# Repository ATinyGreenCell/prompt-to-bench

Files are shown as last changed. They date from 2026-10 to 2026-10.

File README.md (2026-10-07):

# Prompt to Bench: language models as a no-CAD entry point to 3D printing for biology labs



**Sebastian S. Cocioba** ([ORCID 0000-0002-6821-2996](https://orcid.org/0000-0002-6821-2996); [@ATinyGreenCell](https://github.com/ATinyGreenCell)), Binomica Labs, and contributors

*Living preprint, v0.2 (7 October 2026). This README **is** the paper. Corrections, tasks, designs, models and languages are welcome; see [How to contribute](#how-to-contribute). How it was built, prompt by prompt, is in the [build log](meta/BUILD_LOG.md).*

> **In this repository:** the paper (this page) · [student tutorial](tutorial/README.md) and [setup guide](tutorial/SETUP.md) · [16 parametric OpenSCAD lab designs](designs/) · [the Prompt-to-Bench benchmark](bench/) · [`scadreport`](tools/scadreport.py), a geometry-feedback tool for any chatbot · [audits](meta/audits/) · licences: text CC BY 4.0, designs CERN-OHL-P-2.0, code MIT.

---

## Abstract

Biology labs run on small plastic parts: tube racks, gel combs, adapters, knobs, brackets and housings. A desktop 3D printer makes them for cents, but designing them has required CAD skills most biologists never learn. Language models lower that barrier when the CAD is written as code: the user describes a part in words and measured numbers, the model writes an OpenSCAD program, and the user renders, checks and prints it. We describe this workflow and the practices we use to make it reliable, and release 16 parametric, geometry-checked designs across four kinds of lab prints (benchware, tools, quick fixes and parts of instruments; 33.7 h and about US$13 of PLA on a Prusa MK4), a benchmark that scores model-written OpenSCAD against hidden geometric checks, and a tool that measures the part a model actually built. Two hosted models passed nearly every task: Claude Sonnet 5.5 16 of 16 on the first try, Claude Haiku 4.5 14 of 16 within three attempts. None of the open-weight models (0.4-6.6 GB) we ran offline on a 2022 laptop CPU passed a task (the Qwen3.5 9B run is still being completed): the code models mostly wrote syntax OpenSCAD cannot parse and repeated the same file after feedback, and the reasoning models ran out of tokens. The best small models (Gemma 4 E2B and E4B) rendered most parts but rarely got their dimensions right. With this protocol, no open-weight model small enough for a typical student laptop is yet a usable design assistant; with a hosted model, the workflow already produces correct parts. We have not yet tested it with users who lack CAD experience.

---

## 1. Introduction

Every biology lab depends on a long tail of small, specific objects: a rack for the tubes this lab actually uses, a comb for a home-made gel tray, an adapter between two consumables, a replacement for the knob that cracked. Commercial versions are expensive, slow to arrive or not made at all. A decade of "open labware" has shown that printed and open-source equipment can match commercial tools at a fraction of the cost ([Pearce 2012](#pearce2012); [Baden et al. 2015](#baden2015); [Coakley & Hurt 2016](#coakley2016); [Pearce 2020](#pearce2020)), and that it matters most where budgets and supply chains are thinnest ([Maia Chagas 2018](#maiachagas2018); [Wenzel 2023](#wenzel2023)). In one collection of 26 printable lab items, which this author co-wrote, printed versions cost on average 8.18% of their commercial equivalents ([McNair et al. 2024](#mcnair2024)).

The printer is no longer the bottleneck; design is. One of the most widely used scripting tools for parametric open labware is **OpenSCAD** ([OpenSCAD developers](#openscad); [Machado et al. 2019](#machado2019)), in which a part is a short program of solids, Boolean operations and loops. It underlies the OpenFlexure microscope ([Collins et al. 2020](#collins2020)), the FlyPi ([Maia Chagas et al. 2017](#maiachagas2017)), a syringe-pump library ([Wijnen et al. 2014](#wijnen2014)), printable optics ([Zhang et al. 2013](#zhang2013)) and a steady stream of recent biology tools ([Subbaraman et al. 2024](#subbaraman2024); [Keene-Snickers et al. 2025](#keenesnickers2025); [Yamazaki et al. 2025](#yamazaki2025); [Bhupathi et al. 2026](#bhupathi2026); [Algarín et al. 2026](#algarin2026)). Its users find spatial reasoning, validation and debugging the hard parts ([Gonzalez Avila et al. 2024](#gonzalezavila2024)).

Because OpenSCAD designs are text, a language model can draft them from a plain-language description. GPT-4 has been used this way for microfluidic components ([Nelson et al. 2023](#nelson2023)), benchmarks of frontier models find OpenSCAD among the most reliable code-CAD formats ([Jones et al. 2025](#jones2025); [Yang et al. 2026](#yang2026)), and OpenSCAD's developers are building an experimental assistant that talks to a local model by default ([OpenSCAD GSoC 2026](#openscadai2026)). In our lab, a hosted frontier model (Claude) and OpenSCAD now take routine parts from idea to a print-ready file in minutes, which is what prompted this paper.

Access to that combination is uneven. In 2025, 2.2 billion people were offline, and fixed broadband cost more than a quarter of average income in low-income countries ([ITU 2025](#itu2025)). Generative-AI use reached 24.7% of people in the Global North and 14.1% in the Global South ([Microsoft AI Economy Institute 2026](#microsoft2026)). Hosted models cost money, are not offered everywhere ([Anthropic, n.d.](#anthropicregions)), charge more per word for many non-English languages ([Ahia et al. 2023](#ahia2023)) and can change availability at short notice ([Anthropic 2026](#anthropic2026)); non-native English speakers already pay heavily to do science in English ([Amano et al. 2023](#amano2023)). **Open-weight** models running offline on a student's laptop could close much of this gap, but there are reasons for doubt: OpenSCAD is a very low-resource programming language ([§5.5](#55-what-to-expect-from-open-models)), and open-weight models, even at 8-70B parameters, have done poorly at CAD code without fine-tuning ([Badagabettu et al. 2024](#badagabettu2024); [Alrashedy et al. 2025](#alrashedy2025); [Dong et al. 2026](#dong2026)).

We ask three practical questions:

1. **Workflow.** What process, prompts and checks let someone without CAD training get a correct, printable lab part from a language model?
2. **Model size.** What is the smallest open-weight model that is useful for this, offline, on an ordinary laptop?
3. **Language.** Does writing the request in Spanish, Hindi or Swahili change the outcome? (We could test this only for one hosted model.)

**Contributions.**

- A workflow and best-practice rules, with a copy-paste starter prompt ([§3](#3-the-workflow), [§4](#4-best-practices)).
- 16 parametric OpenSCAD lab designs in four categories ([§2](#2-what-labs-print-four-kinds-of-parts), [`designs/`](designs/)).
- `scadreport`, a tool that reports what an OpenSCAD file actually builds - size, holes, spacing, overhangs - in text any chatbot can read ([`tools/`](tools/)).
- **Prompt-to-Bench-16**, 16 design requests with hidden, symmetry-aware geometric checks ([§5](#5-benchmark-prompt-to-bench-16)).
- An evaluation of 14 open-weight models running CPU-only and offline, with two hosted Claude models as a reference and a language ablation ([§6](#6-results)).
- A student tutorial ([`tutorial/`](tutorial/README.md)) and a public log of how this repository was built with an AI assistant ([`meta/`](meta/)).

## 2. What labs print: four kinds of parts

| Kind | Examples | What must be right | Typical risk |
|---|---|---|---|
| **Benchware** (holds, organises, stores) | tube and slide racks, plate-format holders, pipette stands | hole counts, spacing, standard footprints (e.g. ANSI/SLAS microplate) | low - wrong sizes waste plastic |
| **Tools** (used in a protocol) | gel combs, micropestles, funnels, sowing templates | key dimensions, surface finish, materials | low-moderate - contamination, chemical attack |
| **Quick fixes** (replace or adapt a part) | knobs, tube adapters, hose barbs, clips | a precise fit to an existing object | moderate - fit and load |
| **Full hardware** (parts of instruments) | stirrer housings, motor brackets, enclosures, gel tanks | interfaces, fasteners, assembly, electronics | higher - mechanical, electrical, biosafety ([§8](#8-safety-and-responsibility)) |

Our 16 designs cover all four kinds (Figure 1). Each is one OpenSCAD file with every dimension as a named parameter in [Customizer](https://files.openscad.org/documentation/manual/Customizer.html) sections, modelled in print orientation, with print, fit and safety notes in its header. All print without supports; the only bridges are short (at most about 6 mm): the ceilings of the knob and adapter bores, the crowns of the bracket's M3 holes and the enclosure's cable hole, and the slide rack's drain channels. Sliced with PrusaSlicer ([Prusa Research](#prusaslicer)) for an Original Prusa MK4 with the stock 0.20 mm profile, the set takes 33.7 h and 508 g of PLA, about US$13 (Table 1).

The library has two versions on purpose. The benchmark's answer keys are frozen in [`bench/reference/`](bench/reference/): each is exactly what its prompt asks for. The files in [`designs/`](designs/) are their lab-ready successors, revised after a mechanical and biological audit and an adversarial review ([`meta/audits/`](meta/audits/)): wider clearances for tubes, slots that drain, standoffs so stirrer magnets clear the plate, a gel tank whose electrodes sit under the buffer, and explicit warnings where a part could be misused (for example, never spin the tube adapter in a centrifuge). The designs are geometry-checked and sliced; physical print-and-fit validation is in progress.

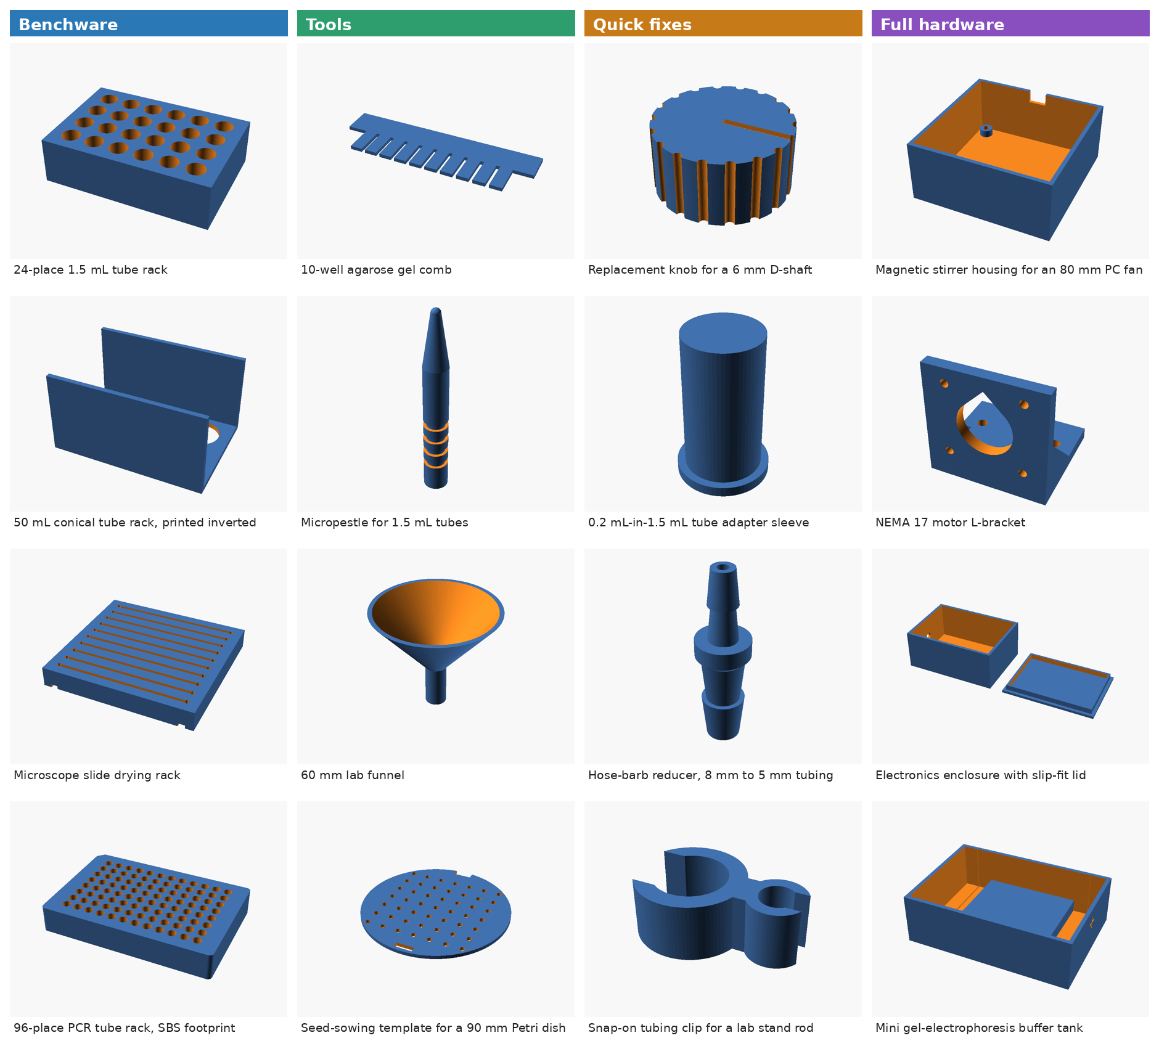
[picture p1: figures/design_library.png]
Renders of the 16 designs in four columns: benchware, tools, quick fixes, full hardware


**Figure 1.** The 16 lab-ready designs in [`designs/`](designs/).

<details>
<summary><b>Table 1.</b> Print-time and filament estimates, Original Prusa MK4 (click to expand)</summary>

<!-- AUTO:table-prints -->
| Part | Kind | Print time | PLA (g) | Material cost (US$) |
|---|---|---:|---:|---:|
| 24-place 1.5 mL tube rack | Benchware | 5h 26m 54s | 78.7 | 1.97 |
| 50 mL conical tube rack, printed inverted | Benchware | 4h 9m 34s | 69.0 | 1.73 |
| Microscope slide drying rack | Benchware | 2h 46m 43s | 45.6 | 1.14 |
| 96-place PCR tube rack, SBS footprint | Benchware | 8h 8m 41s | 92.9 | 2.32 |
| 10-well agarose gel comb | Tools | 11m 32s | 2.7 | 0.07 |
| Micropestle for 1.5 mL tubes | Tools | 26m 34s | 1.9 | 0.05 |
| 60 mm lab funnel | Tools | 37m 44s | 9.3 | 0.23 |
| Seed-sowing template for a 90 mm Petri dish | Tools | 50m 24s | 11.8 | 0.30 |
| Replacement knob for a 6 mm D-shaft | Quick fixes | 21m 7s | 5.0 | 0.12 |
| 0.2 mL-in-1.5 mL tube adapter sleeve | Quick fixes | 10m 41s | 1.5 | 0.04 |
| Hose-barb reducer, 8 mm to 5 mm tubing | Quick fixes | 18m 33s | 1.7 | 0.04 |
| Snap-on tubing clip for a lab stand rod | Quick fixes | 6m 49s | 1.5 | 0.04 |
| Magnetic stirrer housing for an 80 mm PC fan | Full hardware | 3h 7m 49s | 53.9 | 1.35 |
| NEMA 17 motor L-bracket | Full hardware | 59m 51s | 14.2 | 0.35 |
| Electronics enclosure with slip-fit lid | Full hardware | 1h 40m 19s | 33.9 | 0.85 |
| Mini gel-electrophoresis buffer tank | Full hardware | 4h 18m 57s | 84.4 | 2.11 |
| **All 16 parts** | | **33.7 h** | **508** | **12.71** |
<!-- /AUTO:table-prints -->

PrusaSlicer 2.9.6, stock "0.20mm SPEED @MK4 0.4" profile and "Prusament PLA @PG" for every part - not the finer per-part settings some headers recommend, which take longer. Mass assumes 1.24 g/cm³; cost assumes US$25/kg. Reproduce with `python tools/slice_library.py`.
</details>

## 3. The workflow

```mermaid
flowchart LR
    A["1 Measure<br/>calipers, photos"] --> B["2 Specify<br/>starter prompt + numbers"]
    B --> C["3 Generate<br/>model writes .scad"]
    C --> D{"4 Render + check<br/>OpenSCAD + scadreport"}
    D -- "errors or wrong numbers" --> E["5 Feed back<br/>paste messages / report"]
    E --> C
    D -- "matches the spec" --> F["6 Slice<br/>PrusaSlicer"]
    F --> G["7 Print a test coupon"]
    G --> H{"Fits?"}
    H -- "no: change a parameter" --> D
    H -- "yes" --> I["8 Print, use, share<br/>.scad + settings + photo"]
```

**Figure 2.** The model does the CAD; the person measures, checks and decides. Steps 4-5 can be run by an agent such as Claude Code or by hand with any chatbot.

Whatever the model, two features of the loop do most of the work.

**The specification carries the knowledge.** The user gives measured numbers, the print orientation and the coordinate frame ("the base lies on the bed at z = 0"). The model is never asked to remember a tube diameter or a fan's hole pattern; even standard dimensions - ANSI/SLAS microplate footprints, 80 mm fan holes, NEMA 17 bolt patterns - go into the request ([ANSI/SLAS 2004](#slas2004); [SUNON](#sunon); [Oriental Motor](#orientalmotor)).

**The model must be shown what it built.** A language model cannot see its part. When OpenSCAD fails, its messages go back to the model. When the file renders but the part is wrong, the useful feedback is a measurement, not "it's wrong". `scadreport` renders the file and reports whether it is one watertight solid, its bounding box, volume, bed contact and overhangs, and horizontal slices at up to ten representative heights - each listing every hole's shape, size and grid spacing. For a rack whose pitch and hole depth came out wrong:

```
BOUNDING BOX: X -53.00 .. 53.00 (size 106.00) | Y -36.00 .. 36.00 (size 72.00) | Z 0.00 .. 30.00 (size 30.00) mm
  z=1.50: 1 solid region [...]; 24 holes: 24 x circle d=11.19 [6 x 4 grid (X x Y), pitch X 15.00 / Y 15.00, ...]
  z=15.00: 1 solid region [...]; 24 holes: 24 x circle d=11.19 [6 x 4 grid (X x Y), pitch X 15.00 / Y 15.00, ...]
```

The request asked for a 16 mm pitch and a 5 mm solid floor. The report shows a 15 mm pitch and holes at z = 1.5, so the floor is missing. The report knows nothing about the request, so it works for any part.

## 4. Best practices

These rules come from our own use of the workflow, the benchmark and the literature, and complement general guides to 3D printing in chemistry and biology labs ([Pamidi et al. 2024](#pamidi2024); [Saggiomo 2022](#saggiomo2022)).

1. **Measure; don't rely on memory - yours or the model's.** Give caliper numbers for everything that must fit.
2. **State the print orientation and the frame.** Say which face is on the bed at z = 0 and which way is +X. Many "wrong" parts are right shapes, upside down or in the wrong place.
3. **Use a starter prompt.** It fixes the style: millimetres, named parameters, built-in OpenSCAD only, cutters that overshoot faces, `$fn` for round holes, loops for arrays ([`bench/prompts/system.md`](bench/prompts/system.md)). Best-practice lists in the prompt also helped GPT-4 in earlier CAD work ([Makatura et al. 2023](#makatura2023)).
4. **Once a design works, change its numbers - don't regenerate it.** The `.scad` file becomes a template for the next lab.
5. **Check every part against the request.** Paste OpenSCAD's messages or a `scadreport` back into the chat when something is wrong.
6. **Print a coupon first.** A 2-3 mm slice with the critical holes takes minutes. FDM holes print undersized ([Slic3r manual](#slic3r)): start at about 0.3-0.5 mm clearance per side for parts that should drop in (tubes in racks), 0.2-0.3 mm for sliding fits, and calibrate for your printer and material: accuracy depends on speed, temperature and layer height ([Prusa Research, n.d.](#prusamodeling); [Popescu et al. 2023](#popescu2023); [Li et al. 2025](#li2025)).
7. **Design for the printer.** A flat face on the bed, overhangs under about 45°, no long bridges, walls of at least two extrusion widths. Print upside down when that removes supports; four of our designs (the 50 mL rack, the tube adapter, the enclosure lid and the stirrer housing) are modelled that way.
8. **Choose material for the lab.** PLA softens around 55-60 °C: no autoclaves, hot baths or heat blocks. Printed PETG, PP and PC also deformed in 121 °C autoclave tests ([Pérez Davila et al. 2021](#perezdavila2021); [Rynio et al. 2022](#rynio2022); [Popescu et al. 2025](#popescu2025)); PETG's heat deflection temperature is 68 °C ([Prusament TDS](#prusament)). Let agarose cool to 50-60 °C before it meets a printed comb. Brief wipes with 70% ethanol, isopropanol or dilute hypochlorite are fine on PLA ([Vaňková et al. 2020](#vankova2020)); long soaks weaken parts ([Kaptan 2025](#kaptan2025)), and PETG is attacked by acetone, phenol and chloroform.
9. **Know what not to print.** No rotors or adapters for commercial centrifuges ([Eppendorf](#eppendorf)), pressure vessels, mains-powered enclosures without proper electrical design ([IEC 61010-1](#iec61010)), or anything that touches patients ([§8](#8-safety-and-responsibility)).
10. **Share the source, not just the STL.** The `.scad` file is the source of open hardware ([Bonvoisin et al. 2017](#bonvoisin2017); [Diederich et al. 2022](#diederich2022)). Add print settings, a photo, and the model and prompt that produced it.
11. **Keep private work local.** Do not paste unpublished or client designs into hosted services you do not control.
12. **Pick the model for the job.** In our tests only the hosted models produced correct parts. Small open-weight models are worth trying offline, but check everything they produce, and expect to fix the code yourself ([§6](#6-results)).

## 5. Benchmark: Prompt-to-Bench-16

### 5.1 Tasks

Each task is a request as a careful student would write it after measuring: dimensions in millimetres, the print orientation, the frame where it matters, and plain-language features. There are four tasks per category (Table 2), covering blind and through holes, 1-D and 2-D arrays (up to 96 holes in the ANSI/SLAS footprint), slots, teeth, revolved profiles, polar arrays, D-shaped bores, open rings, horizontal holes, multi-part layouts and a clearance fit. Prompts and checks are in [`bench/tasks.yaml`](bench/tasks.yaml); the frozen answer keys are in [`bench/reference/`](bench/reference/).

| Category | Task | What it exercises |
|---|---|---|
| Benchware | 24-place 1.5 mL tube rack | block, blind holes, 6 x 4 grid |
| Benchware | 50 mL conical tube rack, printed inverted | print orientation, through holes, walls |
| Benchware | Microscope slide drying rack | ten 1.6 mm slots |
| Benchware | 96-place PCR tube rack, SBS footprint | standard footprint, 96-hole grid, orientation chamfer |
| Tools | 10-well agarose gel comb | flat 2-D profile, tooth array |
| Tools | Micropestle for 1.5 mL tubes | stacked primitives, cone, grooves at given heights |
| Tools | 60 mm lab funnel | hollow solid of revolution, open ends |
| Tools | Seed-sowing template for a 90 mm Petri dish | disc, 49-hole grid, orientation notch |
| Quick fixes | Replacement knob for a 6 mm D-shaft | D-shaped bore, 18-groove polar array, aligned pointer |
| Quick fixes | 0.2 mL-in-1.5 mL tube adapter sleeve | concentric cylinders, upside-down printing |
| Quick fixes | Hose-barb reducer, 8 mm to 5 mm tubing | revolved sawtooth profile, through bore |
| Quick fixes | Snap-on tubing clip for a lab stand rod | 2-D Booleans, open rings, explicit coordinates |
| Full hardware | Magnetic stirrer housing for an 80 mm PC fan | shelled box, bolt pattern, cable notch |
| Full hardware | NEMA 17 motor L-bracket | horizontal holes, bolt patterns, gussets |
| Full hardware | Electronics enclosure with slip-fit lid | two bodies, 0.2 mm clearance |
| Full hardware | Mini gel-electrophoresis buffer tank | internal platform, chambers, holes |

**Table 2.** The 16 tasks. They test whether a model follows a specification; the lab-ready parts in [`designs/`](designs/) differ where real use called for it ([§2](#2-what-labs-print-four-kinds-of-parts)).

### 5.2 Hidden geometric checks

The model never sees the checks. A candidate is rendered with OpenSCAD's Manifold kernel ([Lalish et al.](#manifold)), normalised (bounding-box centre at the origin in XY, lowest point at z = 0) and tested with:

- **global checks:** bounding box, number of bodies, watertightness, volume relative to the reference;
- **horizontal sections:** number of solid regions and holes, hole sizes, positions and grids, section areas;
- **probe points** that must be solid or empty (notches, chamfers, horizontal holes);
- **line and arc probes** that count solid intervals (comb teeth, grip grooves).

Position-dependent checks are evaluated under all eight symmetries of the bed (90° rotations and mirroring), which do not change how a part prints, and the best match is kept. A part passes only if every check passes. Absolute tolerances are 0.15-0.9 mm (most 0.3-0.5 mm, tighter for the 0.2 mm clearance fit, looser where the prompt allows two readings), plus 4-35% on areas and volumes; they are set to accept every correct reading of the prompt, not to mimic print accuracy.

[`bench/build_refs.py`](bench/build_refs.py) confirms that the references pass their own checks, still pass after rotation, mirroring and translation, fail when scaled by 3%, and pass no other task's checks. These tests show the checks are self-consistent, not that every correct design passes or every wrong one fails. Two audits found both kinds of error. One false negative: "a 1.6 mm wall everywhere" on the funnel can be measured horizontally (our reference) or perpendicular to the cone (+24% volume), so we widened that task's volume tolerance. Three false positives: a comb with nine teeth or the wrong tooth pitch, a pestle with one grip groove instead of four, and a knob with a 7 mm bore instead of 12 mm all passed (two comb checks shared a name, so one silently replaced the other). We fixed the checks and added these parts to `build_refs.py` as known-wrong cases that must fail. Re-checking every saved hosted-model attempt with [`bench/rescore.py`](bench/rescore.py) changed the funnel verdict and no other; re-checking the local-model attempts changed partial scores but no verdict. Building the checks also caught an error in our own design: a 7 x 7 grid at 10 mm pitch put the corner holes through the rim of the 85 mm seed template.

### 5.3 Protocol

- **Prompt:** the same system prompt ([`bench/prompts/system.md`](bench/prompts/system.md)) for every model, then the task text.
- **Code extraction:** the longest OpenSCAD-labelled fenced block (otherwise any fenced block, the text after an unclosed fence, or the whole reply if it contains OpenSCAD calls). Local replies stop once a complete block has arrived, so in practice their first block counts.
- **Feedback:** a part that fails gets one message and another try, up to three attempts: OpenSCAD's own errors when nothing rendered, otherwise the `scadreport` measurement with an instruction to compare it with the specification. The hidden checks are never shown, but they decide *whether* feedback is sent, so "passed within three attempts" is an optimistic bound on what a user who must spot errors alone would get.
- **Local models:** Ollama 0.30.11, 4-bit weights (Q4_K_M), temperature 0.2, top-p 0.95, a fixed seed per attempt, 8,192-token context, "thinking" requested off where a model supports the switch. Replies end at 2,048 tokens, when a complete OpenSCAD block has arrived, or when the model repeats itself verbatim. Qwen2.5-Coder 3B and 7B ran with an earlier 1,024-token cap that never applied (their longest reply was 723 tokens); we raised the cap after a first pass cut off Gemma 4 E4B and others, and reran those models.
- **Hosted reference:** Claude Haiku 4.5 and Claude Sonnet 5.5 through the Claude Code command line in print mode, with our system prompt, tools disabled and otherwise vendor defaults: the API's default temperature (the CLI cannot set it) and no seed. Haiku used extended thinking (median about 10,000 output tokens per reply, range 4,100-23,500); Sonnet answered directly (320-1,430 tokens, 3.5-11.5 s per reply). This is Claude at its defaults, not an equal-cost comparison.
- **Hardware:** a 2022 laptop, Intel Core i7-1260P (12 cores, 16 threads), 16 GB RAM, no discrete GPU, Ubuntu, OpenSCAD 2026.10.01 (development snapshot), PrusaSlicer 2.9.6. Local models ran one at a time, but some runs overlapped other work on the same laptop (for example the hosted language run, whose rendering uses the CPU), so timings are indicative (roughly ±20%), not clean benchmarks.

### 5.4 Models

<!-- AUTO:table-models -->
| Model | Family | Parameters | Download | Licence |
|---|---|---|---:|---|
| Qwen2.5-Coder 0.5B (`qwen2.5-coder:0.5b`) | Qwen2.5-Coder | 0.49B | 0.4 GB | Apache-2.0 |
| Qwen2.5-Coder 1.5B (`qwen2.5-coder:1.5b`) | Qwen2.5-Coder | 1.54B | 0.99 GB | Apache-2.0 |
| Qwen2.5 1.5B (general) (`qwen2.5:1.5b`) | Qwen2.5 | 1.54B | 0.99 GB | Apache-2.0 |
| Qwen3.5 2B (`qwen3.5:2b-q4_K_M`) | Qwen3.5 | 2.27B | 1.9 GB | Apache-2.0 |
| Qwen2.5-Coder 3B (`qwen2.5-coder:3b`) | Qwen2.5-Coder | 3.09B | 1.9 GB | Qwen Research (non-commercial) |
| Llama 3.2 3B (`llama3.2:3b`) | Llama 3.2 | 3.21B | 2 GB | Llama 3.2 Community |
| Granite 4.2 3B (`granite4.2:3b`) | Granite 4.2 | 3B | 2.2 GB | Apache-2.0 |
| Ministral 3 3B (`ministral-3:3b`) | Ministral 3 | 3.4B | 3 GB | Apache-2.0 |
| Qwen3.5 4B (`qwen3.5:4b-q4_K_M`) | Qwen3.5 | 4.66B | 3.3 GB | Apache-2.0 |
| Gemma 4 E2B (`gemma4:e2b-it-q4_K_M`) | Gemma 4 | 2.3B effective, 5.1B with per-layer embeddings | 4.6 GB | Apache-2.0 |
| Qwen2.5-Coder 7B (`qwen2.5-coder:7b`) | Qwen2.5-Coder | 7.61B | 4.7 GB | Apache-2.0 |
| LFM2.5 8B-A1B (MoE) (`lfm2.5:8b-a1b-q4_K_M`) | LFM2.5 | 8.3B total, ~1.5B active per token | 5.2 GB | LFM Open v1.0 (revenue cap) |
| Gemma 4 E4B (`gemma4:e4b-it-q4_K_M`) | Gemma 4 | 4.5B effective, 8B with per-layer embeddings | 6.6 GB | Apache-2.0 |
| Qwen3.5 9B (`qwen3.5:9b-q4_K_M`) | Qwen3.5 | 9.65B | 6.6 GB | Apache-2.0 |
| Claude Haiku 4.5 (hosted) (`claude:claude-haiku-4-5`) | Claude | - | hosted | proprietary API |
| Claude Sonnet 5.5 (hosted) (`claude:claude-sonnet-5-5`) | Claude | - | hosted | proprietary API |
<!-- /AUTO:table-models -->

The 14 local models come from eight families: Qwen2.5-Coder ([Hui et al. 2024](#hui2024)), Qwen2.5 ([Qwen Team 2024](#qwen2024)), Qwen3.5 ([Qwen Team 2026](#qwen2026)), Gemma 4 ([Gemma Team 2026](#gemma2026)), Ministral 3 ([Liu et al. 2026](#liu2026)), Granite 4.2 ([IBM Granite Team 2026](#ibm2026)), LFM2.5 ([Liquid AI 2026](#liquid2026)) and Llama 3.2 ([Meta 2024](#meta2024)), all run through Ollama ([Ollama](#ollama)) on llama.cpp ([Gerganov et al.](#llamacpp)) as 4-bit GGUF files ([Kawrakow 2023](#kawrakow2023)). Sizes are Ollama download sizes; parameter counts and licences are from the model cards (accessed 5 October 2026). "Open-weight" is not open source, and licences matter for labs that sell services: the Qwen2.5-Coder 3B weights are non-commercial, LFM2.5 has a revenue threshold, and Llama 3.2 has its own licence ([Qwen 2024](#qwen3blicense); [Liquid AI 2026](#liquid2026); [Meta 2024](#meta2024)). Tags and digests are in [`bench/logs/model_digests.txt`](bench/logs/model_digests.txt).

### 5.5 What to expect from open models

**OpenSCAD is a low-resource language.** In The Stack, an openly licensed corpus used to pretrain many code models, OpenSCAD is about 0.03 GB of compressed data, against about 47 GB for Python and 1.6 GB for Lua ([Kocetkov et al. 2022](#kocetkov2022); [Lozhkov et al. 2024](#lozhkov2024)) - and Lua is itself the usual example of a "low-resource" language ([Cassano et al. 2024](#cassano2024)). Quantised 7B code models on a CPU-only laptop score below 50% on Lua benchmarks ([Nyamsuren 2025](#nyamsuren2025)).

**Open models have done poorly at CAD code without fine-tuning.** CodeLlama-70B produced "extremely bad" FreeCAD output ([Badagabettu et al. 2024](#badagabettu2024)); open models compiled less often than GPT-4 ([Alrashedy et al. 2025](#alrashedy2025)); on a 2026 assembly benchmark, open-weight models of 8B parameters and up scored about 3-4% against about 20% for the best closed models ([Dong et al. 2026](#dong2026)). Small-model successes come from fine-tuning on narrow CAD datasets ([Rukhovich et al. 2025](#rukhovich2025); [Govindarajan et al. 2026](#govindarajan2026); [Xie & Ju 2025](#xie2025)). We test models as a student would download them.

**"Minimal viable", defined before analysing local results.** A minimally viable local model passes at least **half of the 16 tasks within three attempts**, runs on a 16 GB laptop without a GPU, and needs a median of at most **10 minutes per task**; the minimal one is the smallest download that meets all three.

## 6. Results

### 6.1 Overall

<!-- AUTO:table-main -->
| Model | Download | Licence | Pass, 1st try | Pass, ≤3 tries (95% CI) | Renders 1st try | Median min/task | Tokens/s | Same code after feedback |
|---|---:|---|---:|---:|---:|---:|---:|---:|
| Claude Haiku 4.5 (hosted) | hosted | proprietary API | 11/16 | 14/16 (64-97%) | 15/16 | 1.9 | - | 2/8 |
| Claude Sonnet 5.5 (hosted) | hosted | proprietary API | 16/16 | 16/16 (81-100%) | 16/16 | 0.1 | - | 0/0 |
| Qwen2.5-Coder 0.5B | 0.4 GB | Apache-2.0 | 0/16 | 0/16 (0-19%) | 0/16 | 0.8 | 37.7 | 24/32 |
| Qwen2.5 1.5B (general) | 0.99 GB | Apache-2.0 | 0/16 | 0/16 (0-19%) | 2/16 | 1.0 | 22.0 | 27/32 |
| Qwen2.5-Coder 1.5B | 0.99 GB | Apache-2.0 | 0/16 | 0/16 (0-19%) | 1/16 | 1.4 | 12.8 | 32/32 |
| Qwen2.5-Coder 3B | 1.9 GB | Qwen Research (non-commercial) | 0/16 | 0/16 (0-19%) | 3/16 | 1.9 | 10.7 | 31/32 |
| Qwen3.5 2B | 1.9 GB | Apache-2.0 | 0/16 | 0/16 (0-19%) | 0/16 | 6.3 | 18.4 | 0/32 |
| Llama 3.2 3B | 2.0 GB | Llama 3.2 Community | 0/16 | 0/16 (0-19%) | 8/16 | 2.2 | 10.3 | 6/32 |
| Granite 4.2 3B | 2.2 GB | Apache-2.0 | 0/16 | 0/16 (0-19%) | 2/16 | 14.8 | 6.9 | 0/32 |
| Ministral 3 3B | 3.0 GB | Apache-2.0 | 0/16 | 0/16 (0-19%) | 1/16 | 3.6 | 9.0 | 0/32 |
| Qwen3.5 4B | 3.3 GB | Apache-2.0 | 0/16 | 0/16 (0-19%) | 1/16 | 15.2 | 8.3 | 0/32 |
| Gemma 4 E2B | 4.6 GB | Apache-2.0 | 0/16 | 0/16 (0-19%) | 12/16 | 3.6 | 18.6 | 3/32 |
| Qwen2.5-Coder 7B | 4.7 GB | Apache-2.0 | 0/16 | 0/16 (0-19%) | 1/16 | 3.1 | 5.8 | 32/32 |
| LFM2.5 8B-A1B (MoE) | 5.2 GB | LFM Open v1.0 (revenue cap) | 0/16 | 0/16 (0-19%) | 0/16 | 5.1 | 20.8 | 0/32 |
| Gemma 4 E4B | 6.6 GB | Apache-2.0 | 0/16 | 0/16 (0-19%) | 9/16 | 6.1 | 11.7 | 5/32 |
| Qwen3.5 9B *(partial)* | 6.6 GB | Apache-2.0 | 0/2 | 0/2 (0-66%) | 1/2 | 17.2 | 4.7 | 1/4 |
<!-- /AUTO:table-main -->

**Table 3.** Main results. "Renders 1st try" means the first file produced a non-empty solid, correct or not. Intervals are Wilson 95% intervals over the 16 tasks of a single run (over the tasks completed, for partial rows); they do not include run-to-run variation. "Same code after feedback" counts repair attempts that returned a byte-identical file.

The hosted models are at or near the ceiling. Claude Sonnet 5.5 passed all 16 tasks on the first try; Claude Haiku 4.5 passed 11 on the first try and 14 within three attempts, failing the 96-place rack (one chamfer probe) and the enclosure (a lid with a solid floor under its lip, +14% volume). With one run each, the two cannot be ranked (paired exact test on first tries, p = 0.06); the task set is too easy to separate hosted models of this class.

No local model passed a task. Every complete local model scored 0 of 16 (Wilson upper bound 19%), so none met the viability bar in [§5.5](#55-what-to-expect-from-open-models). The Qwen3.5 9B run is still being completed (2 of 16 tasks so far); its partial row is marked.

### 6.2 How far the local models got

<!-- AUTO:fig-tiers -->
<picture>
  <source media="(prefers-color-scheme: dark)" srcset="figures/fig_tiers_dark.png">
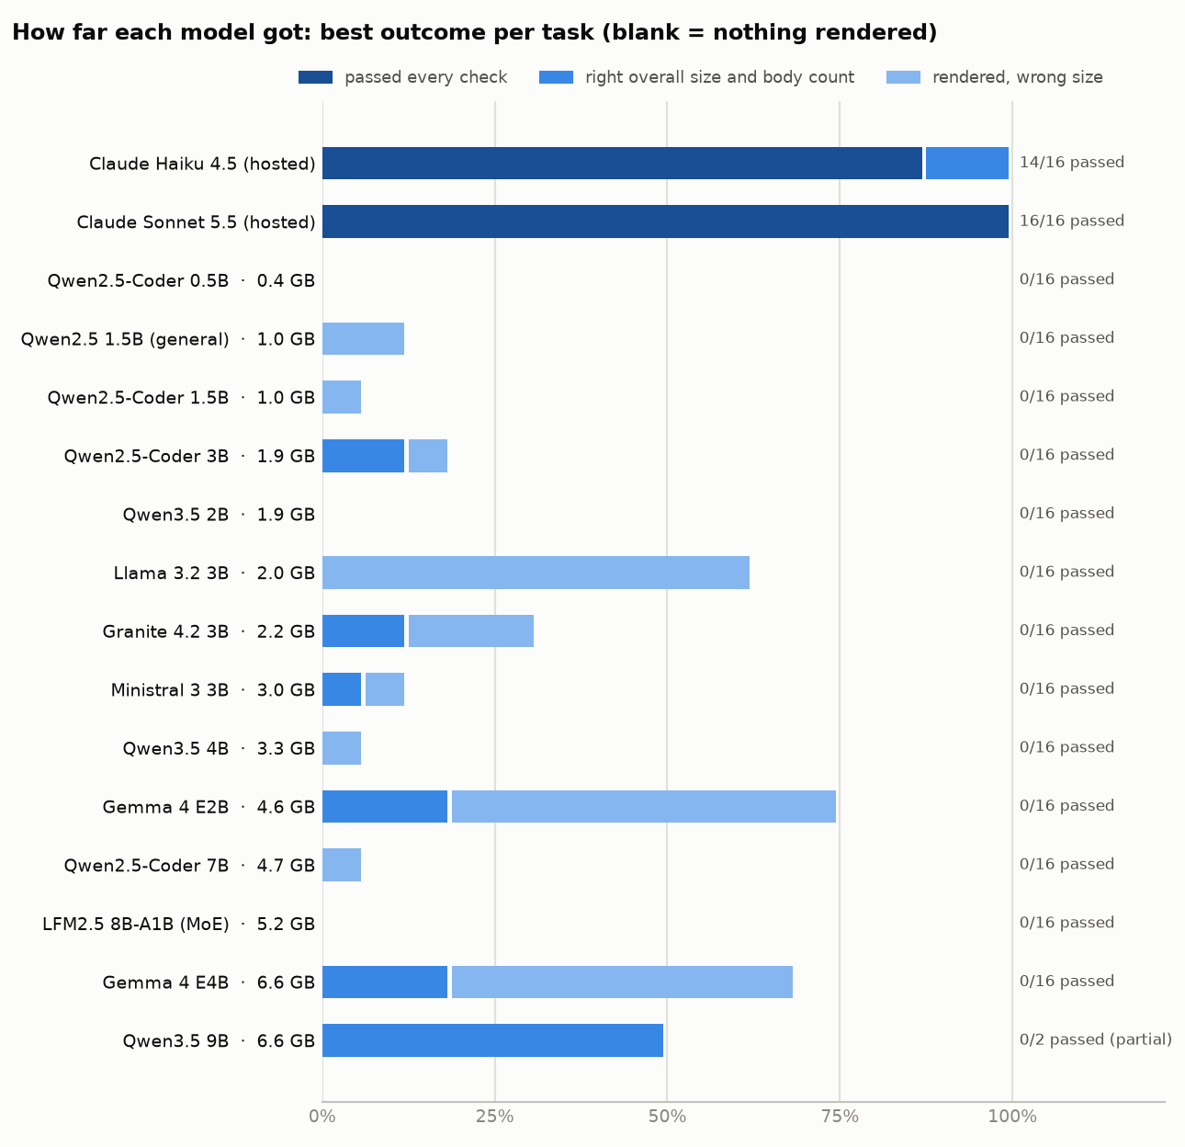
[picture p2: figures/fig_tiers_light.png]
Stacked bars of the best outcome each model reached per task
  
</picture>
<!-- /AUTO:fig-tiers -->

**Figure 3.** The best outcome each model reached per task, from nothing rendered (blank) to a part with the right overall size and body count, to a pass. Local models are ordered by download size.

<!-- AUTO:table-graded -->
| Model | Rendered (any try) | Right size and body count | Passed | Tasks with ≥ half the checks | First file treats geometry as a value | Attempts cut off (cap or loop) | Same code after feedback |
|---|---:|---:|---:|---:|---:|---:|---:|
| Claude Haiku 4.5 (hosted) | 16/16 | 16/16 | 14/16 | 16/16 | 0/16 | 0/24 | 2/8 |
| Claude Sonnet 5.5 (hosted) | 16/16 | 16/16 | 16/16 | 16/16 | 0/16 | 0/16 | 0/0 |
| Qwen2.5-Coder 0.5B | 0/16 | 0/16 | 0/16 | 0/16 | 0/16 | 27/48 | 24/32 |
| Qwen2.5 1.5B (general) | 2/16 | 0/16 | 0/16 | 0/16 | 6/16 | 15/48 | 27/32 |
| Qwen2.5-Coder 1.5B | 1/16 | 0/16 | 0/16 | 0/16 | 14/16 | 3/48 | 32/32 |
| Qwen2.5-Coder 3B | 3/16 | 2/16 | 0/16 | 2/16 | 11/16 | 0/48 | 31/32 |
| Qwen3.5 2B | 0/16 | 0/16 | 0/16 | 0/16 | 3/16 | 42/48 | 0/32 |
| Llama 3.2 3B | 10/16 | 0/16 | 0/16 | 0/16 | 2/16 | 1/48 | 6/32 |
| Granite 4.2 3B | 5/16 | 2/16 | 0/16 | 1/16 | 8/16 | 37/48 | 0/32 |
| Ministral 3 3B | 2/16 | 1/16 | 0/16 | 1/16 | 8/16 | 1/48 | 0/32 |
| Qwen3.5 4B | 1/16 | 0/16 | 0/16 | 0/16 | 5/16 | 39/48 | 0/32 |
| Gemma 4 E2B | 12/16 | 3/16 | 0/16 | 6/16 | 2/16 | 1/48 | 3/32 |
| Qwen2.5-Coder 7B | 1/16 | 0/16 | 0/16 | 0/16 | 15/16 | 0/48 | 32/32 |
| LFM2.5 8B-A1B (MoE) | 0/16 | 0/16 | 0/16 | 0/16 | 0/16 | 41/48 | 0/32 |
| Gemma 4 E4B | 11/16 | 3/16 | 0/16 | 6/16 | 3/16 | 5/48 | 5/32 |
| Qwen3.5 9B *(partial)* | 1/2 | 1/2 | 0/2 | 1/2 | 0/2 | 1/6 | 1/4 |
<!-- /AUTO:table-graded -->

**Table 4.** Graded outcomes. "Right size and body count": the bounding box and number of separate solids match, on any attempt. "Geometry as a value": the first file assigns shapes to variables (`rack = cube(...)`), which OpenSCAD cannot parse. "Cut off": attempts that ended at the token cap or in a verbatim loop.

The zeros hide three different failures:

- **Code models write a different language.** Qwen2.5-Coder 1.5B, 3B and 7B wrote "geometry as a value" in 11-15 of 16 first files - OpenSCAD written as if it were Python or JavaScript - and almost never produced a part.
- **Feedback changed nothing for them.** The same three models returned byte-identical code in 31-32 of 32 repair attempts, even with a new random seed; Qwen2.5-Coder 0.5B and the general Qwen2.5 1.5B did so in 24 and 27 of 32. A bare "syntax error, line 18" from OpenSCAD did not tell them what to change.
- **Reasoning models ran out of tokens.** With thinking requested off, Qwen3.5 and Granite 4.2 reasoned inside code comments, and LFM2.5 ignored the switch and wrote `<think>` reasoning in every reply. In the four complete runs (Qwen3.5 2B and 4B, Granite 4.2, LFM2.5), 37-42 of 48 attempts ended at the 2,048-token cap or in a loop. Their scores say as much about the protocol as about their design ability.

The closest were the Gemma 4 models (E2B and E4B), which rendered 11-12 of 16 parts and met half the checks on 6 tasks, but got the overall size right on only 3. The single best local attempt (Gemma 4 E4B, micropestle) failed one check: its grip grooves were 1.5 mm deep instead of 1 mm.

<!-- AUTO:fig-outcomes -->
<picture>
  <source media="(prefers-color-scheme: dark)" srcset="figures/fig_outcomes_dark.png">
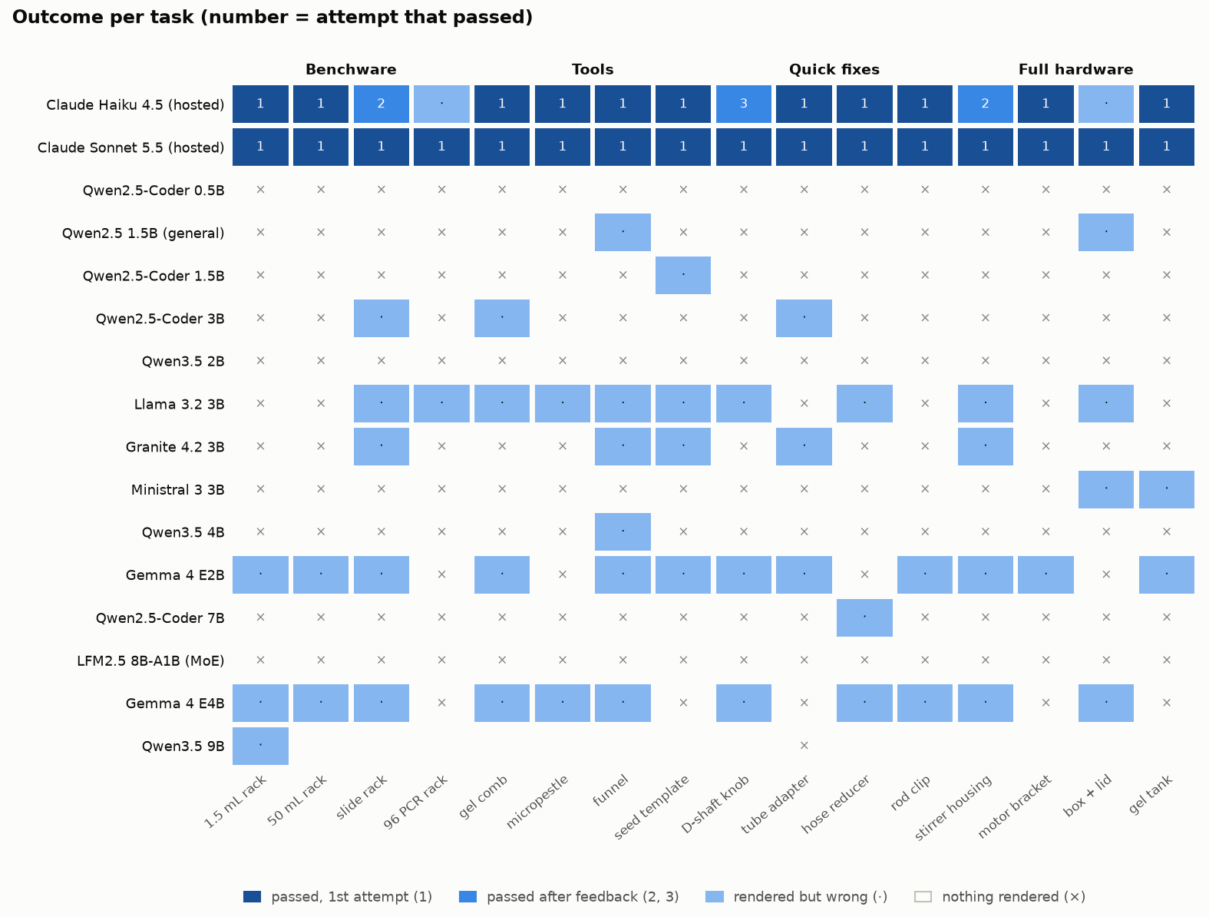
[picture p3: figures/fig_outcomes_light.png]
Grid of outcomes per model and task
  
</picture>
<!-- /AUTO:fig-outcomes -->

**Figure 4.** Outcome per model and task. Numbers give the attempt that passed; "·" rendered but never matched the specification; "×" nothing rendered.

<!-- AUTO:table-categories -->
| Model | Benchware | Tools | Quick fixes | Full hardware |
|---|---:|---:|---:|---:|
| Claude Haiku 4.5 (hosted) | 3/4 | 4/4 | 4/4 | 3/4 |
| Claude Sonnet 5.5 (hosted) | 4/4 | 4/4 | 4/4 | 4/4 |
| Qwen2.5-Coder 0.5B | 0/4 | 0/4 | 0/4 | 0/4 |
| Qwen2.5 1.5B (general) | 0/4 | 0/4 | 0/4 | 0/4 |
| Qwen2.5-Coder 1.5B | 0/4 | 0/4 | 0/4 | 0/4 |
| Qwen2.5-Coder 3B | 0/4 | 0/4 | 0/4 | 0/4 |
| Qwen3.5 2B | 0/4 | 0/4 | 0/4 | 0/4 |
| Llama 3.2 3B | 0/4 | 0/4 | 0/4 | 0/4 |
| Granite 4.2 3B | 0/4 | 0/4 | 0/4 | 0/4 |
| Ministral 3 3B | 0/4 | 0/4 | 0/4 | 0/4 |
| Qwen3.5 4B | 0/4 | 0/4 | 0/4 | 0/4 |
| Gemma 4 E2B | 0/4 | 0/4 | 0/4 | 0/4 |
| Qwen2.5-Coder 7B | 0/4 | 0/4 | 0/4 | 0/4 |
| LFM2.5 8B-A1B (MoE) | 0/4 | 0/4 | 0/4 | 0/4 |
| Gemma 4 E4B | 0/4 | 0/4 | 0/4 | 0/4 |
| Qwen3.5 9B | 0/1 | - | 0/1 | - |
<!-- /AUTO:table-categories -->

**Table 5.** Tasks passed within three attempts, by category (out of 4).

<!-- AUTO:table-failures -->
| Model | truncated | no code | syntax error | render error | no solid | timeout | wrong geometry | pass |
|---|---:|---:|---:|---:|---:|---:|---:|---:|
| Claude Haiku 4.5 (hosted) | 0 | 0 | 1 | 0 | 0 | 0 | 4 | 11 |
| Claude Sonnet 5.5 (hosted) | 0 | 0 | 0 | 0 | 0 | 0 | 0 | 16 |
| Qwen2.5-Coder 0.5B | 9 | 0 | 7 | 0 | 0 | 0 | 0 | 0 |
| Qwen2.5 1.5B (general) | 5 | 0 | 9 | 0 | 0 | 0 | 2 | 0 |
| Qwen2.5-Coder 1.5B | 1 | 0 | 11 | 1 | 2 | 0 | 1 | 0 |
| Qwen2.5-Coder 3B | 0 | 0 | 12 | 0 | 1 | 0 | 3 | 0 |
| Qwen3.5 2B | 15 | 0 | 0 | 1 | 0 | 0 | 0 | 0 |
| Llama 3.2 3B | 1 | 0 | 5 | 1 | 1 | 0 | 8 | 0 |
| Granite 4.2 3B | 12 | 0 | 1 | 0 | 1 | 0 | 2 | 0 |
| Ministral 3 3B | 0 | 0 | 13 | 0 | 2 | 0 | 1 | 0 |
| Qwen3.5 4B | 14 | 0 | 1 | 0 | 0 | 0 | 1 | 0 |
| Gemma 4 E2B | 0 | 0 | 4 | 0 | 0 | 0 | 12 | 0 |
| Qwen2.5-Coder 7B | 0 | 0 | 15 | 0 | 0 | 0 | 1 | 0 |
| LFM2.5 8B-A1B (MoE) | 16 | 0 | 0 | 0 | 0 | 0 | 0 | 0 |
| Gemma 4 E4B | 3 | 0 | 3 | 1 | 0 | 0 | 9 | 0 |
| Qwen3.5 9B | 0 | 0 | 1 | 0 | 0 | 0 | 1 | 0 |
<!-- /AUTO:table-failures -->

**Table 6.** Where each model's first attempt stopped: cut off (token cap or loop), no code, a syntax or other render error, no solid (empty or 2-D), a rendered part with the wrong geometry, or a pass.

### 6.3 Language

<!-- AUTO:fig-languages -->
<picture>
  <source media="(prefers-color-scheme: dark)" srcset="figures/fig_languages_dark.png">
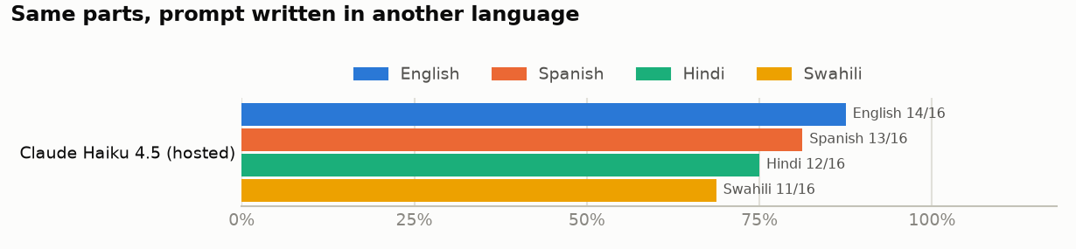
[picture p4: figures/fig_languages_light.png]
Pass rates for prompts in English, Spanish, Hindi and Swahili
  
</picture>
<!-- /AUTO:fig-languages -->

With Claude Haiku 4.5, requests in Spanish, Hindi and Swahili (system prompt in English) passed 13, 12 and 11 of 16 tasks within three attempts, against 14 in English; first-try passes were 12, 10 and 6 against 11. With one sample per task at the default temperature, none of these differences is statistically detectable (paired exact McNemar tests, p ≥ 0.375 for passes, p = 0.125 for Swahili first tries). Some failures recurred with the same failing check - the NEMA 17 bracket in all three translations (English passed it first time), and the 96-place rack's chamfer in English, Hindi and Swahili - so not all of the variation is sampling noise. We did not run the language ablation on local models, which passed nothing in English. A bug overwrote the generated code of the Spanish and Hindi runs (their scores were recorded first), so those two runs cannot be re-checked; it is fixed for future runs.

## 7. Global access

**Cost.** A Prusa MK4S costs about US$650-1,000 (kit vs assembled) and capable budget printers about US$200 ([Prusa Research](#prusaprice); [Bambu Lab](#bambuprice); [Creality](#crealityprice)). After that, parts are cheap: our 16-part library uses about US$13 of PLA. OpenSCAD, PrusaSlicer, Ollama and open-weight models are free; hosted models need a subscription or per-token payment, often in a currency labs cannot easily use.

**Connectivity.** The local workflow runs offline once installed; the obstacle is the one-time download of the software plus 0.4-6.6 GB per model. In nine of ten low-income economies a 5 GB mobile data basket costs more than 10% of monthly income ([ITU 2025b](#itu2025b)), so teaching labs, maker spaces and networks such as TReND ([Baden et al. 2020](#baden2020)) or GOSH ([GOSH 2017](#gosh2017)) should share models on USB drives or local mirrors.

**Availability.** Major hosted providers exclude a small set of countries and territories, including China, Russia and Iran ([Anthropic, n.d.](#anthropicregions); [OpenAI, n.d.](#openairegions); [Google, n.d.](#googleregions)); most low-income countries are supported. Access can still change: in June 2026 a US government directive suspended two frontier Anthropic models for "any foreign national" for 18 days while other models stayed available ([Anthropic 2026](#anthropic2026)). A local model cannot be switched off this way, and it keeps unpublished designs on the user's machine.

**Language.** Language models perform worse in many non-English languages ([Ahuja et al. 2023](#ahuja2023)), and code generation degrades more steeply for small open models than for frontier ones as prompts move to lower-resource languages ([Raihan et al. 2025](#raihan2025)). Our one-model test found no detectable effect ([§6.3](#63-language)).

**Hardware.** The test machine is a mid-range 2022 ultrabook with 16 GB of RAM; the 6.6 GB models ran on it alongside a desktop session with an 8,192-token context. We did not test larger models.

**Where this leaves a student without a subscription.** Today, the reliable path still runs through a hosted model; free tiers of hosted chatbots may be enough for simple parts (we did not test them). The parts of the workflow that do not depend on the model - measuring, writing a precise request, checking with `scadreport`, printing coupons, editing parameters - transfer completely, and so does the design library.

## 8. Safety and responsibility

- **Materials and sterilisation.**
  - Fresh FDM prints can be close to sterile off the nozzle ([Neches et al. 2016](#neches2016)), but handling ends that, and layer lines harbour biofilm ([Hall et al. 2021](#hall2021)). Ethanol disinfects but does not kill spores, so anything that touches media or cultures should be soaked, dried in a hood and treated as single use.
  - Printed PLA cannot be autoclaved ([Neijhoft et al. 2023](#neijhoft2023)), and printed PETG, PP and PC deformed at 121 °C in tests ([Rynio et al. 2022](#rynio2022); [Popescu et al. 2025](#popescu2025)); moulded PP labware is a different matter and is routinely autoclaved.
  - UV-C degrades PETG faster than PLA ([Amza et al. 2021](#amza2021)), and resin (SLA) prints can be toxic to sensitive organisms ([Macdonald et al. 2016](#macdonald2016)). Test printed materials in your own system before trusting them with cells or organisms.
- **Centrifuges.** Manufacturers require their own accessories ([Eppendorf](#eppendorf)), and biosafety guidance relies on certified sealed rotors or safety cups ([CDC & NIH 2020](#bmbl2020)). Our tube adapter fits a 1.5 mL rotor bore by design, so its header says, in capitals, never to spin it.
- **Electrical hardware.** Mains-powered devices fall under IEC 61010-1 ([IEC 2010](#iec61010)); keep DIY electronics at safe low voltage behind certified supplies. Gel electrophoresis runs at hazardous DC voltages: our tank does not include a lid or interlock, and its header says not to connect a power supply until one is built.
- **Printing.** Printers emit ultrafine particles and volatile organic compounds, more with ABS than with PLA ([Azimi et al. 2016](#azimi2016)); follow institutional ventilation guidance ([NIOSH 2020](#niosh2020)).
- **Distribution.** Open-hardware certification is not safety certification ([OSHWA 2026](#oshwa2026)). From 9 December 2026 the EU Product Liability Directive treats "digital manufacturing files" as products ([EU 2024](#eu2024)); anyone distributing printable designs commercially in the EU should take advice (this is not legal advice). Document hazards with each design, as hardware journals require ([HardwareX template](#hardwarex)).

## 9. Limitations

- **Scale.** Sixteen tasks, one run per model, one computer. Intervals are wide and do not include run-to-run variation.
- **Protocol choices decide some results.** Thinking was requested off and replies were capped at 2,048 tokens, so models that reason before answering (Qwen3.5, Granite 4.2, LFM2.5) were mostly cut off; with thinking on and a larger budget they might do better, at a large cost in CPU time. Local models ran at temperature 0.2, which made several repeat themselves exactly; Claude ran at its default temperature. Feedback was triggered by the hidden checks (an optimistic bound).
- **Who wrote the tasks.** The tasks, checks, reference designs and translations were drafted with Claude (Anthropic), which may favour Claude's phrasing; the hosted models are near ceiling, so the benchmark cannot rank them. Independent tasks would help.
- **The harness evolved during the study.** We fixed bugs and added robustness after the first runs; re-checking every saved attempt with the final checker changed one verdict (§5.2). Two language runs cannot be re-checked (§6.3).
- **Geometry is not function.** Passing means the part matches the request, not that it works; the designs have not yet been printed and measured systematically.
- **No user study.** We did not test the workflow with students or biologists who lack CAD experience; that it suits them is the author's experience, not a measured result.
- **Best-case prompts.** Our requests are complete and precise; real ones are vaguer.
- **Translations** have not yet been reviewed by native speakers.
- **Snapshot.** These results describe models available on 5 October 2026.

## 10. Conclusion

A language model plus OpenSCAD can already turn a measured, written request into a correct lab part - when the model is a hosted frontier model, the request carries measured numbers and the print orientation, and every part is checked before it is printed. Whether people without CAD training can run this loop unaided is the next thing to test. Under our protocol, no open-weight model small enough for a typical student laptop was yet a usable design assistant: the code models write OpenSCAD as if it were another language and do not use error messages, and the reasoning models run out of tokens before they finish. The gap is specific enough to close - examples of correct OpenSCAD in the prompt, error messages translated into instructions, thinking budgets that fit a laptop, or small models fine-tuned on code like the designs released here - and the benchmark is cheap to rerun on new models, hardware and languages.

---

## How to contribute

This is a living paper; contributions are credited and substantial ones earn authorship ([CONTRIBUTING.md](CONTRIBUTING.md)). Most useful:

- **Run the benchmark on your hardware** (`bench/run_bench.py`), especially in low-resource settings, and send the `results/` folder in a pull request.
- **Add a model** (one line in [`bench/models.yaml`](bench/models.yaml) plus a run) or **a task** from your lab ([`bench/tasks.yaml`](bench/tasks.yaml), validated with `python bench/build_refs.py`).
- **Review or add a language** in [`bench/prompts/translations.yaml`](bench/prompts/translations.yaml).
- **Print and measure** a design and report the fit with photos and caliper readings.
- **Translate the tutorial.**

## Reproducing this paper

```bash
python3 -m venv .venv && .venv/bin/pip install -r requirements.txt
.venv/bin/python bench/test_harness.py        # robustness tests (fake model, real OpenSCAD)
.venv/bin/python bench/build_refs.py          # validate the checker against the frozen references
bash bench/logs/pull_models.sh                # download the 14 local models (0.4-6.6 GB each)
bash bench/run_main_local.sh                  # local models via Ollama (hours on a CPU)
.venv/bin/python bench/analyze.py             # tables and figures in this README
```

Details, including the hosted reference and the language ablation, are in [`bench/README.md`](bench/README.md).

## Author contributions and AI use

**S. S. Cocioba:** conceptualisation, scope and design decisions, supervision of all AI-assisted work, review of code, designs and text, validation, and writing (review and editing); responsible for the content.

**AI use.** Claude (Anthropic; Claude Opus 5.5 in Claude Code) drafted the benchmark code, reference designs, translations, figures, tutorial and much of this text, and ran the literature search and three audits of the claims, code and designs ([`meta/audits/`](meta/audits/)), under the author's direction. The audits were run in fresh sessions instructed to find faults, but they are the same model family that wrote the work, so they are not independent review. Every reference was checked against a primary record (Crossref, PubMed, arXiv, the publisher or official documentation) on 5 October 2026. The prompts and the assistant's replies that built this repository are published, lightly redacted, in [`meta/BUILD_LOG.md`](meta/BUILD_LOG.md). Following COPE and ICMJE guidance, the AI is not listed as an author. No client or confidential work was used.

**Funding.** This work was self-funded by the author, an independent researcher at Binomica Labs; it received no grant or institutional funding.

**Competing interests.** S. S. Cocioba is a co-author of [McNair et al. 2024](#mcnair2024), cited here. No other competing interests.

## How to cite

Cocioba SS (2026). *Prompt to Bench: language models as a no-CAD entry point to 3D printing for biology labs.* Zenodo. https://doi.org/10.5281/zenodo.23198097

This DOI always resolves to the latest version; each release also has its own DOI (v0.1.0: [10.5281/zenodo.23198098](https://doi.org/10.5281/zenodo.23198098); v0.2.0: [10.5281/zenodo.23212435](https://doi.org/10.5281/zenodo.23212435)). Machine-readable metadata: [`CITATION.cff`](CITATION.cff).

---

## References

Ahia O, Kumar S, Gonen H, Kasai J, Mortensen D, Smith N, Tsvetkov Y (2023). Do all languages cost the same? Tokenization in the era of commercial language models. *Proc. EMNLP 2023*, 9904-9923. https://doi.org/10.18653/v1/2023.emnlp-main.614

Ahuja K, Diddee H, Hada R, Ochieng M, Ramesh K, Jain P, et al. (2023). MEGA: Multilingual evaluation of generative AI. *Proc. EMNLP 2023*, 4232-4267. https://doi.org/10.18653/v1/2023.emnlp-main.258

Algarín A, Cabrera PL, Scagliusi SF, Daza P, Yúfera A, Martín D (2026). An accessible and open-source workflow for fabrication of custom PDMS culture chambers using 3D printing. *MethodsX* 17:104091. https://doi.org/10.1016/j.mex.2026.104091

Alrashedy K, Tambwekar P, Zaidi ZH, Langwasser M, Xu W, Gombolay M (2025). Generating CAD code with vision-language models for 3D designs. *ICLR 2025*. https://arxiv.org/abs/2410.05340

Amano T, Ramírez-Castañeda V, Berdejo-Espinola V, Borokini I, Chowdhury S, Golivets M, et al. (2023). The manifold costs of being a non-native English speaker in science. *PLOS Biology* 21(7):e3002184. https://doi.org/10.1371/journal.pbio.3002184

Amza CG, Zapciu A, Baciu F, Vasile MI, Popescu D (2021). Aging of 3D printed polymers under sterilizing UV-C radiation. *Polymers* 13(24):4467. https://doi.org/10.3390/polym13244467

ANSI/SLAS (2004, reaffirmed 2012). ANSI SLAS 1-2004: Footprint dimensions; ANSI SLAS 4-2004: Well positions for microplates. Society for Laboratory Automation and Screening. https://www.slas.org/SLAS/assets/File/public/standards/ANSI_SLAS_1-2004_FootprintDimensions.pdf ; https://www.slas.org/SLAS/assets/File/public/standards/ANSI_SLAS_4-2004_WellPositions.pdf

Anthropic (n.d.). Supported countries and regions. https://www.anthropic.com/supported-countries (accessed 5 Oct 2026)

Anthropic (2026). Statement on the US government directive to suspend access to Fable 5 and Mythos 5 (12 June 2026); Redeploying Fable 5 (30 June 2026). https://www.anthropic.com/news/fable-mythos-access ; https://www.anthropic.com/news/redeploying-fable-5

Azimi P, Zhao D, Pouzet C, Crain NE, Stephens B (2016). Emissions of ultrafine particles and volatile organic compounds from commercially available desktop three-dimensional printers with multiple filaments. *Environmental Science & Technology* 50(3):1260-1268. https://doi.org/10.1021/acs.est.5b04983

Badagabettu A, Yarlagadda SS, Barati Farimani A (2024). Query2CAD: Generating CAD models using natural language queries. arXiv:2406.00144. https://arxiv.org/abs/2406.00144

Baden T, Chagas AM, Gage GJ, Marzullo TC, Prieto-Godino LL, Euler T (2015). Open Labware: 3-D printing your own lab equipment. *PLoS Biology* 13(3):e1002086. https://doi.org/10.1371/journal.pbio.1002086

Baden T, Maina MB, Maia Chagas A, Mohammed YG, Auer TO, Silbering A, et al. (2020). TReND in Africa: toward a truly global (neuro)science community. *Neuron* 107(3):412-416. https://doi.org/10.1016/j.neuron.2020.06.026

Bambu Lab (n.d.). A1 mini. https://us.store.bambulab.com/products/a1-mini (accessed 5 Oct 2026; US$219)

Bhupathi M, Hegde S, Molloy JC, Devarapu GCR (2026). MobileLAMP: A low-cost, portable incubation device for isothermal nucleic acid amplification. *PLOS One* 21(4):e0346874. https://doi.org/10.1371/journal.pone.0346874

Bonvoisin J, Mies R, Boujut J-F, Stark R (2017). What is the "source" of open source hardware? *Journal of Open Hardware* 1(1):5. https://doi.org/10.5334/joh.7

Cassano F, Gouwar J, Lucchetti F, Schlesinger C, Freeman A, Anderson CJ, et al. (2024). Knowledge transfer from high-resource to low-resource programming languages for code LLMs. *Proc. ACM Program. Lang.* 8(OOPSLA2):677-708. https://doi.org/10.1145/3689735

CDC & NIH (2020). *Biosafety in Microbiological and Biomedical Laboratories*, 6th edition. https://www.cdc.gov/labs/pdf/SF__19_308133-A_BMBL6_00-BOOK-WEB-final-3.pdf

Coakley M, Hurt DE (2016). 3D printing in the laboratory: maximize time and funds with customized and open-source labware. *Journal of Laboratory Automation* 21(4):489-495. https://doi.org/10.1177/2211068216649578

Collins JT, Knapper J, Stirling J, Mduda J, Mkindi C, Mayagaya V, et al. (2020). Robotic microscopy for everyone: the OpenFlexure microscope. *Biomedical Optics Express* 11(5):2447-2460. https://doi.org/10.1364/BOE.385729

Creality (n.d.). Ender-3 V3 SE. https://store.creality.com/products/ender-3-v3-se-3d-printer (accessed 5 Oct 2026; US$199)

Diederich B, Müllenbroich C, Vladimirov N, Bowman R, Stirling J, Reynaud EG, et al. (2022). CAD we share? Publishing reproducible microscope hardware. *Nature Methods* 19(9):1026-1030. https://doi.org/10.1038/s41592-022-01484-5

Dong X, Li Z, Wu X-M (2026). MUSE: Benchmarking manufacturable, functional, and assemblable text-to-CAD generation. arXiv:2605.28579. https://arxiv.org/abs/2605.28579

Eppendorf (2018). Centrifuge 5424 R operating manual (5404 900.023-08/052018), safety instructions on accessories and spare parts. https://www.eppendorf.com/product-media/doc/en/330723/Centrifugation_Operating-manual_Centrifuge-5424-R.pdf

European Union (2024). Directive (EU) 2024/2853 on liability for defective products. *Official Journal of the EU*, L, 18.11.2024. https://eur-lex.europa.eu/legal-content/EN/TXT/HTML/?uri=OJ:L_202402853

Gemma Team (2026). Gemma 4 technical report. arXiv:2607.02770. https://arxiv.org/abs/2607.02770 ; licence: https://ai.google.dev/gemma/docs/gemma_4_license

Gerganov G and the ggml authors (2023-2026). llama.cpp (MIT). https://github.com/ggml-org/llama.cpp

Gonzalez Avila JF, Pietrzak T, Girouard A, Casiez G (2024). Understanding the challenges of OpenSCAD users for 3D printing. *Proc. CHI 2024*, 1-20. https://doi.org/10.1145/3613904.3642566

Google (n.d.). Available regions for Google AI Studio and Gemini API. https://ai.google.dev/gemini-api/docs/available-regions (accessed 5 Oct 2026)

Gathering for Open Science Hardware (2017). Global Open Science Hardware Roadmap. https://openhardware.science/global-open-science-hardware-roadmap/

Govindarajan P, Baldelli D, Pathak J, Fournier Q, Chandar S (2026). CADmium: Fine-tuning code language models for text-driven sequential CAD design. *Transactions on Machine Learning Research* (01/2026). https://openreview.net/forum?id=lExqWvQht8

Hall DC, Palmer P, Ji HF, Ehrlich GD, Król JE (2021). Bacterial biofilm growth on 3D-printed materials. *Frontiers in Microbiology* 12:646303. https://doi.org/10.3389/fmicb.2021.646303

HardwareX (2019). Article template. Zenodo. https://doi.org/10.5281/zenodo.3364475

Hui B, Yang J, Cui Z, Yang J, Liu D, Zhang L, et al. (2024). Qwen2.5-Coder technical report. arXiv:2409.12186. https://arxiv.org/abs/2409.12186

IBM Granite Team (2026). Granite 4.2 LLMs: how they're built (Hugging Face blog, Aug 2026). https://huggingface.co/blog/ibm-granite/granite-4-2

IEC (2010, amended 2016). IEC 61010-1: Safety requirements for electrical equipment for measurement, control, and laboratory use - Part 1: General requirements. https://webstore.iec.ch/en/publication/4279

ITU (2025). *Measuring digital development: Facts and Figures 2025.* International Telecommunication Union. https://www.itu.int/hub/publication/d-ind-ict_mdd-2025-3/

ITU (2025). *Global Connectivity Report 2025*, Chapter 4: Making connectivity affordable for all. https://www.itu.int/itu-d/reports/statistics/2025/11/17/gcr-2025-chapter-4/

Jones BT, Zhang Z, Hähnlein F, Matusik W, Ahmad M, Kim V, Schulz A (2025). A solver-aided hierarchical language for LLM-driven CAD design. *Computer Graphics Forum* 44(7):e70250. https://doi.org/10.1111/cgf.70250

Kaptan A (2025). Investigation of the effect of exposure to liquid chemicals on the strength performance of 3D-printed parts from different filament types. *Polymers* 17(12):1637. https://doi.org/10.3390/polym17121637

Kawrakow (2023). k-quants (Q4_K and related GGUF quantisation types). llama.cpp pull request #1684. https://github.com/ggml-org/llama.cpp/pull/1684

Keene-Snickers AH, Dunham TJ, Stenglein MD (2025). Experimental assessment of 3D-printed traps and chemical attractants for the collection of wild *Drosophila melanogaster*. *Fly* 19(1):2502184. https://doi.org/10.1080/19336934.2025.2502184

Kocetkov D, Li R, Ben Allal L, Li J, Mou C, Muñoz Ferrandis C, et al. (2022). The Stack: 3 TB of permissively licensed source code. arXiv:2211.15533. https://arxiv.org/abs/2211.15533

Lalish E and Manifold contributors (2022-2026). Manifold geometry library (Apache-2.0). https://github.com/elalish/manifold

Li Y, Molazem A, Kuo HI, Ahmadi V, Shastri VP (2025). Comparative analysis of dimensional accuracy in PLA-based 3D printing: effects of key printing parameters and related variables. *Polymers* 17(12):1698. https://doi.org/10.3390/polym17121698

Liu AH, Khandelwal K, Subramanian S, Jouault V, Rastogi A, Sadé A, et al. (2026). Ministral 3. arXiv:2601.08584. https://arxiv.org/abs/2601.08584

Liquid AI (2026). LFM2.5-8B-A1B: an even better on-device mixture of experts (blog, 28 May 2026), and LFM Open License v1.0. https://www.liquid.ai/blog/lfm2-5-8b-a1b

Lozhkov A, Li R, Ben Allal L, Cassano F, Lamy-Poirier J, Tazi N, et al. (2024). StarCoder 2 and The Stack v2: the next generation. arXiv:2402.19173. https://arxiv.org/abs/2402.19173

Macdonald NP, Zhu F, Hall CJ, Reboud J, Crosier PS, Patton EE, et al. (2016). Assessment of biocompatibility of 3D printed photopolymers using zebrafish embryo toxicity assays. *Lab on a Chip* 16(2):291-297. https://doi.org/10.1039/C5LC01374G

Machado F, Malpica N, Borromeo S (2019). Parametric CAD modeling for open source scientific hardware: comparing OpenSCAD and FreeCAD Python scripts. *PLoS ONE* 14(12):e0225795. https://doi.org/10.1371/journal.pone.0225795

Maia Chagas A, Prieto-Godino LL, Arrenberg AB, Baden T (2017). The €100 lab: a 3D-printable open-source platform for fluorescence microscopy, optogenetics, and accurate temperature control during behaviour of zebrafish, *Drosophila*, and *Caenorhabditis elegans*. *PLoS Biology* 15(7):e2002702. https://doi.org/10.1371/journal.pbio.2002702

Maia Chagas A (2018). Haves and have nots must find a better way: the case for open scientific hardware. *PLoS Biology* 16(9):e3000014. https://doi.org/10.1371/journal.pbio.3000014

Makatura L, Foshey M, Wang B, Hähnlein F, Ma P, Deng B, et al. (2023). How can large language models help humans in design and manufacturing? arXiv:2307.14377; published in two parts in *Harvard Data Science Review* (2024). https://doi.org/10.1162/99608f92.cc80fe30

McNair MC, Cocioba SC, Pietrzyk P, Rife TW (2024). Toward an open-source 3D-printable laboratory. *Applications in Plant Sciences* 12(1):e11562. https://doi.org/10.1002/aps3.11562

Meta (2024). Llama 3.2: revolutionizing edge AI and vision with open, customizable models (25 Sep 2024), and the Llama 3.2 Community License. https://ai.meta.com/blog/llama-3-2-connect-2024-vision-edge-mobile-devices/

Microsoft AI Economy Institute (2026). Global AI adoption in 2025 - a widening digital divide. https://www.microsoft.com/en-us/research/wp-content/uploads/2026/01/Microsoft-AI-Diffusion-Report-2025-H2.pdf

Neches RY, Flynn KJ, Zaman L, Tung E, Pudlo N (2016). On the intrinsic sterility of 3D printing. *PeerJ* 4:e2661. https://doi.org/10.7717/peerj.2661

Neijhoft J, Henrich D, Kammerer A, Janko M, Frank J, Marzi I (2023). Sterilization of PLA after fused filament fabrication 3D printing: evaluation on inherent sterility and the impossibility of autoclavation. *Polymers* 15(2):369. https://doi.org/10.3390/polym15020369

Nelson MD, Goenner BL, Gale BK (2023). Utilizing ChatGPT to assist CAD design for microfluidic devices. *Lab on a Chip* 23(17):3778-3784. https://doi.org/10.1039/D3LC00518F

NIOSH (2020). *3D printing with filaments: health and safety questions to ask.* DHHS (NIOSH) Publication No. 2020-115. https://doi.org/10.26616/NIOSHPUB2020115

Nyamsuren E (2025). Evaluating quantized large language models for code generation on low-resource language benchmarks. *Journal of Computer Languages* 84:101351. https://doi.org/10.1016/j.cola.2025.101351

Ollama (2023-2026). Ollama (MIT). https://github.com/ollama/ollama

OpenAI (n.d.). Supported countries and territories. https://developers.openai.com/api/docs/supported-countries (accessed 5 Oct 2026)

OpenSCAD developers (maintainer M. Kintel). OpenSCAD - the programmers solid 3D CAD modeller (GPL-2.0). https://openscad.org/ ; development snapshot 2026.10.01 used here.

OpenSCAD developers (2026). "Integrate AI chat for helping users creating OpenSCAD scripts", Google Summer of Code 2026 project (opencax/GSoC#113), merged into development snapshots behind the experimental `ai-features` flag (openscad/openscad PRs #6836, #6865, #6881, #6925, #6955). https://github.com/opencax/GSoC/issues/113

Oriental Motor (2023). PKP series stepping motors catalogue 524B, dimensions (NEMA 17: 31 mm bolt pattern, 22 mm pilot). https://www.orientalmotor.com/products/pdfs/2023-2024/524B_PKP_Series.pdf

OSHWA (2026). OSHWA's new Open Healthware certification: how we got here and where we're going (9 Jan 2026). https://oshwa.org/announcements/oshwas-new-open-healthware-certification-how-we-got-here-and-where-were/

Pamidi AS, Spano MB, Weiss GA (2024). A practical guide to 3D printing for chemistry and biology laboratories. *Current Protocols* 4(10):e70036. https://doi.org/10.1002/cpz1.70036

Pearce JM (2012). Building research equipment with free, open-source hardware. *Science* 337(6100):1303-1304. https://doi.org/10.1126/science.1228183

Pearce JM (2020). Economic savings for scientific free and open source technology: a review. *HardwareX* 8:e00139. https://doi.org/10.1016/j.ohx.2020.e00139

Pérez Davila S, González Rodríguez L, Chiussi S, Serra J, González P (2021). How to sterilize polylactic acid based medical devices? *Polymers* 13(13):2115. https://doi.org/10.3390/polym13132115

Popescu D, Amza CG, Marinescu R, Iacob MC, Căruţaşu NL (2023). Investigations on factors affecting 3D-printed holes dimensional accuracy and repeatability. *Applied Sciences* 13(1):41. https://doi.org/10.3390/app13010041

Popescu D, Iacob MC, Marinescu R (2025). Dimensional accuracy of 3D-printed surgical cutting guides after hospital sterilization: a comparative evaluation of ten MEX materials. *3D Printing in Medicine* 11(1):44. https://doi.org/10.1186/s41205-025-00291-w

Prusa Research (2026). PrusaSlicer 2.9.6 (AGPL-3.0). https://github.com/prusa3d/PrusaSlicer

Prusa Research (n.d.). Modeling with 3D printing in mind. Prusa Knowledge Base. https://help.prusa3d.com/article/modeling-with-3d-printing-in-mind_164135 (accessed 5 Oct 2026)

Prusa Research (n.d.). Original Prusa MK4S 3D printer. https://www.prusa3d.com/product/original-prusa-mk4s-3d-printer/ (accessed 5 Oct 2026)

Prusa Polymers (2021-2022). Prusament technical data sheets v1.1: PLA (HDT 55 °C), PETG (HDT 68 °C). https://prusament.com/wp-content/uploads/2022/10/PLA_Prusament_TDS_2021_10_EN.pdf ; https://prusament.com/wp-content/uploads/2022/10/PETG_Prusament_TDS_2021_10_EN.pdf

Qwen (2024). Qwen2.5-Coder-3B-Instruct model card and Qwen Research License. https://huggingface.co/Qwen/Qwen2.5-Coder-3B-Instruct/blob/main/LICENSE

Qwen Team: Yang A, Yang B, Zhang B, Hui B, Zheng B, Yu B, et al. (2024). Qwen2.5 technical report. arXiv:2412.15115. https://arxiv.org/abs/2412.15115

Qwen Team (2026). Qwen3.5: towards native multimodal agents (blog and model cards for Qwen3.5-2B/4B/9B). https://qwen.ai/blog?id=qwen3.5 ; https://huggingface.co/Qwen

Raihan N, Anastasopoulos A, Zampieri M (2025). mHumanEval - a multilingual benchmark to evaluate large language models for code generation. *Proc. NAACL 2025*, 11432-11461. https://doi.org/10.18653/v1/2025.naacl-long.570

Rukhovich D, Dupont E, Mallis D, Cherenkova K, Kacem A, Aouada D (2025). CAD-Recode: reverse engineering CAD code from point clouds. *ICCV 2025*, 9801-9811. https://doi.org/10.1109/ICCV51701.2025.00914

Rynio P, Galant K, Wójcik Ł, Grygorcewicz B, Kazimierczak A, Falkowski A, et al. (2022). Effects of sterilization methods on different 3D printable materials for templates of physician-modified aortic stent grafts used in vascular surgery - a preliminary study. *International Journal of Molecular Sciences* 23(7):3539. https://doi.org/10.3390/ijms23073539

Saggiomo V (2022). A 3D printer in the lab: not only a toy. *Advanced Science* 9(27):2202610. https://doi.org/10.1002/advs.202202610

Slic3r manual (n.d.). Troubleshooting: dimension errors. https://manual.slic3r.org/troubleshooting/dimension-errors

Subbaraman B, de Lange O, Ferguson S, Peek N (2024). The Duckbot: a system for automated imaging and manipulation of duckweed. *PLOS ONE* 19(1):e0296717. https://doi.org/10.1371/journal.pone.0296717

SUNON (n.d.). DC brushless fan & blower catalogue (240-A), 80 x 80 x 25 mm series (mounting holes 71.5 mm). https://www.sunon.com/en/MANAGE/Docs/PRODUCT/286/360/Sunon%20DC%20Brushless%20Fan%20&%20Blower_(240-A).pdf

Vaňková E, Kašparová P, Khun J, Machková A, Julák J, Sláma M, et al. (2020). Polylactic acid as a suitable material for 3D printing of protective masks in times of COVID-19 pandemic. *PeerJ* 8:e10259. https://doi.org/10.7717/peerj.10259

Wenzel T (2023). Open hardware: from DIY trend to global transformation in access to laboratory equipment. *PLOS Biology* 21(1):e3001931. https://doi.org/10.1371/journal.pbio.3001931

Wijnen B, Hunt EJ, Anzalone GC, Pearce JM (2014). Open-source syringe pump library. *PLoS ONE* 9(9):e107216. https://doi.org/10.1371/journal.pone.0107216

Xie H, Ju F (2025). Text-to-CadQuery: a new paradigm for CAD generation with scalable large model capabilities. arXiv:2505.06507. https://arxiv.org/abs/2505.06507

Yamazaki Y, Yuguchi M, Honjo B, Isokawa K (2025). Design and fabrication of customized brain slice matrices using CAD and 3D printing technology. *PLOS ONE* 20(1):e0317616. https://doi.org/10.1371/journal.pone.0317616

Yang Y, Hu Z, Lin Y, Zhou M, Xu J, Zhang F, et al. (2026). P3D-Bench: benchmarking MLLMs for parametric 3D generation and structural reasoning. arXiv:2606.11152. https://arxiv.org/abs/2606.11152

Zhang C, Anzalone NC, Faria RP, Pearce JM (2013). Open-source 3D-printable optics equipment. *PLoS ONE* 8(3):e59840. https://doi.org/10.1371/journal.pone.0059840

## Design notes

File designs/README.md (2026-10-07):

# Design library

Sixteen parametric OpenSCAD designs for biology labs, plus a printer calibration coupon. They started as the benchmark's reference solutions (frozen in [`bench/reference/`](../bench/reference/)) and were then revised for real use after a mechanical and biological audit and an adversarial review ([`meta/audits/`](../meta/audits/)). They are geometry-checked and sliced; physical print-and-fit validation is in progress. Each file:

- is plain OpenSCAD with no libraries;
- keeps its parameters at the top in Customizer sections, so you can change them in **Window → Customizer** without touching the code;
- is modelled in the orientation it prints in;
- stops with a plain message (an `assert`) if you choose parameters that would break the part, such as overlapping holes or a floor under 0.8 mm. `make designs` renders every file with its defaults and with edge-case values.

Licence: [CERN-OHL-P-2.0](../LICENSES/CERN-OHL-P-2.0.txt), a permissive open-hardware licence.

The 16 designs

| Kind | File | Print notes |
|---|---|---|
| Benchware | [`benchware/tube_rack_1p5ml.scad`](benchware/tube_rack_1p5ml.scad) | 11.6 mm holes (0.4 mm per side); about 5.4 h |
| Benchware | [`benchware/conical_rack_50ml.scad`](benchware/conical_rack_50ml.scad) | prints upside down, flip after printing; 31 mm holes for 30 mm Falcon tubes |
| Benchware | [`benchware/slide_drying_rack.scad`](benchware/slide_drying_rack.scad) | edge-only contact and drain holes; check slot width with a real slide |
| Benchware | [`benchware/pcr_tube_rack_sbs.scad`](benchware/pcr_tube_rack_sbs.scad) | full ANSI/SLAS base footprint; fits plate carriers, not magnet stands or lids; about 8 h |
| Tools | [`tools/gel_comb_10well.scad`](tools/gel_comb_10well.scad) | PETG; set tooth length for your tray; pour agarose at 50-60 °C |
| Tools | [`tools/micropestle_1p5ml.scad`](tools/micropestle_1p5ml.scad) | single use; not for TRIzol/phenol; brim |
| Tools | [`tools/lab_funnel_60mm.scad`](tools/lab_funnel_60mm.scad) | true 1.6 mm wall; PETG for water, buffers, ethanol; brim |
| Tools | [`tools/seed_sowing_template.scad`](tools/seed_sowing_template.scad) | 82 mm disc; use under the dish, or soak and use once |
| Quick fixes | [`quick-fixes/dshaft_knob_6mm.scad`](quick-fixes/dshaft_knob_6mm.scad) | measure the shaft (6 mm or 1/4"); PETG near hotplates |
| Quick fixes | [`quick-fixes/pcr_tube_adapter.scad`](quick-fixes/pcr_tube_adapter.scad) | **racks only - never in a centrifuge**; not for heat blocks |
| Quick fixes | [`quick-fixes/hose_barb_reducer_8_5.scad`](quick-fixes/hose_barb_reducer_8_5.scad) | low-pressure lines only; leak-test |
| Quick fixes | [`quick-fixes/rod_tubing_clip.scad`](quick-fixes/rod_tubing_clip.scad) | measure the rod (12 or 12.7 mm) and the tubing OD; PETG |
| Full hardware | [`hardware/stirrer_fan_housing.scad`](hardware/stirrer_fan_housing.scad) | standoffs clear the magnets; 12 V fan and certified supply only |
| Full hardware | [`hardware/nema17_motor_bracket.scad`](hardware/nema17_motor_bracket.scad) | teardrop motor hole; screw the base down first |
| Full hardware | [`hardware/enclosure_box_and_lid.scad`](hardware/enclosure_box_and_lid.scad) | slip-fit lid (0.1 mm for friction); cable hole; fits an Arduino Nano build |
| Full hardware | [`hardware/mini_gel_tank.scad`](hardware/mini_gel_tank.scad) | **lid and interlock not included - do not power it until built**; leak-test |
| Calibration | [`calibration/clearance_coupon.scad`](calibration/clearance_coupon.scad) | print first: measures your printer's press, sliding and loose fits (see [setup guide](../tutorial/SETUP.md#c-calibrate-once-your-printer-facts-card)) |

Print times are PrusaSlicer estimates for an Original Prusa MK4 (0.20 mm SPEED profile). The full table is in the paper (Table 1) and in [`../figures/print_estimates.csv`](../figures/print_estimates.csv).

## Customising

- **In the GUI:** open the file in OpenSCAD and show **Window → Customizer**. Change values, press F6 to render, then F7 to export the STL.
- **From the command line:**

  ```bash
  openscad -D pitch=18 -D hole_d=11.6 -o rack.stl designs/benchware/tube_rack_1p5ml.scad
  ```

- **Check the result** before printing:

  ```bash
  python tools/scadreport.py designs/benchware/tube_rack_1p5ml.scad
  ```

## Safety

Read §8 of the [paper](../README.md#8-safety-and-responsibility) before using printed parts with heat, chemicals, organisms, spinning machinery or electricity. These designs are provided as-is, without warranty, under the terms of the licence.

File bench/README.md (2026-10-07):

# Prompt-to-Bench-16: benchmark

Sixteen biology-lab parts, described in words and numbers. A model writes OpenSCAD, OpenSCAD renders it, and hidden geometric checks decide whether the part matches the request. When it does not, the model gets feedback and another try.

## Files

| File | What it is |
|---|---|
| [`tasks.yaml`](tasks.yaml) | the 16 prompts and their hidden checks |
| [`prompts/system.md`](prompts/system.md) | the system prompt every model receives (also the tutorial's starter prompt) |
| [`prompts/translations.yaml`](prompts/translations.yaml) | the same prompts in Spanish, Hindi and Swahili |
| [`checks.py`](checks.py) | the checker (bbox, bodies, slices, probes, lines, arcs, volume; symmetry-aware) |
| [`reference/`](reference/) | the 16 frozen answer keys (v1); the lab-ready parts in `designs/` have since diverged |
| [`build_refs.py`](build_refs.py) | renders the reference designs and validates the checker against them and against known-wrong parts in [`mutants/`](mutants/) |
| [`rescore.py`](rescore.py) | re-checks every saved attempt of a run with the current checker and reports changed verdicts |
| [`reference_stats.json`](reference_stats.json) | reference volumes, slice areas and design-frame centres (generated) |
| [`run_bench.py`](run_bench.py) | runs models: Ollama (local) or `claude:<model>` via the Claude Code CLI |
| [`models.yaml`](models.yaml) | model metadata: sizes, parameters, licences |
| [`analyze.py`](analyze.py) | builds `results/summary.csv`, the figures and the README results blocks |
| `run_main_local.sh`, `run_lang.sh` | the exact commands used for the paper |
| `results/<run>/` | one JSON line per conversation, plus every generated `.scad` and raw reply |

## Quick start

```bash
python3 -m venv .venv && .venv/bin/pip install -r requirements.txt
.venv/bin/python bench/build_refs.py                  # sanity-check the checker (about 30 s)
ollama pull qwen2.5-coder:7b
.venv/bin/python bench/run_bench.py --run mytest --models qwen2.5-coder:7b --tasks tube_rack_1p5ml gel_comb_10well
.venv/bin/python bench/analyze.py --no-readme --runs mytest
```

You need OpenSCAD on your `PATH`. A development snapshot with the Manifold backend is strongly recommended, because CGAL renders of the 96-hole rack take minutes. You also need Ollama for local models.

## Protocol (as used in the paper)

- **Prompt:** the system prompt plus the task prompt.
  - Local models run at temperature 0.2 and top-p 0.95, with a fixed seed per attempt, an 8,192-token context and "thinking" requested off (LFM2.5 ignores the switch).
  - Replies are streamed and end at 2,048 tokens (1,024 for the Qwen2.5-Coder 3B and 7B runs, which never reached it), at the first complete OpenSCAD code block, or when the model repeats itself verbatim.
- **Code extraction:** the longest OpenSCAD-labelled fenced block; otherwise the longest fenced block of any label, the text after an unclosed fence, or the whole reply if it contains OpenSCAD calls. `<think>` reasoning is removed first.
- **Render:** OpenSCAD with the default Manifold backend and a 120 s timeout.
- **Feedback** (`--feedback report`, the default; up to `--max-repairs 2` rounds):
  - When the file did not render: OpenSCAD's messages.
  - When it rendered but failed: the generic `tools/scadreport.py` measurement report, which never mentions the hidden checks.
  - `--feedback generic` replaces the report with "it does not match the specification, try again", which measures how much the measurements themselves help.
- **Pass:** every check passes. We also record partial scores, failure stages, tokens and timings.

## Robustness

- **Runtime errors are never scored.** If Ollama or the Claude CLI fails (server restart, dropped connection, rate limit), the request is retried with back-off. If it still fails, the task is skipped *without* a record, so a later run picks it up. Three runtime errors in a row stop the run.
- **Resumable and crash-safe.** Each conversation is appended with `fsync`. A line damaged by a power cut is dropped on the next start and that task reruns. Run the same command again to resume.
- **One writer per run.** A lock file refuses a second `run_bench.py` on the same `--run` folder.
- **No sleep.** `run_main_local.sh` and `run_lang.sh` hold a `systemd-inhibit` lock (where available), so the laptop does not suspend mid-run.
- **Library use is flagged.** Attempts that `include`/`use` an external library are flagged (`uses_library`), because their result depends on what is installed locally.
- `python bench/test_harness.py` (or `make test`) exercises all of the above with a fake model.
- **Resume keys ignore settings.** A run folder is resumed by (model, task, sample, language, feedback); use a new `--run` name when you change `--num-predict`, `--think` or the temperature.
- After any change to `checks.py` or `tasks.yaml`, run `python bench/rescore.py <run> --dry-run` to see which verdicts would change, then without `--dry-run` to apply.

## Check types

A check is written in the *design frame*: the part as the prompt describes it, with its lowest point at z = 0. Candidates are normalised by bounding-box centre. The position-dependent checks are tried under the eight bed symmetries (90° rotations and mirroring), and the best match is kept.

| Check | Example | Meaning |
|---|---|---|
| `bbox` | `{size: [106, 72, 30], tol: 0.5}` | overall size (X and Y may be swapped) |
| `bodies` | `2` | number of separate solids |
| `volume` | `{rel_tol: 0.05}` | volume within 5% of the reference |
| `slice` | `{z: 15, islands: 1, holes: 24, hole_d: [11.2, 0.4], hole_grid: {...}}` | horizontal cross-section at height z |
| `probes` | `{solid: [[x,y,z]], empty: [[x,y,z]]}` | points that must be inside or outside material |
| `line` | `{z, from, to, intervals: 10, length: [5, 0.3]}` | count of solid stretches along a line (teeth, slots) |
| `arc` | `{z, center, r, gaps: 18}` | count of gaps around a circle (grip grooves) |

## Adding results from your machine

Run with a unique `--run` name and open a pull request with the `results/<run>/` folder. Add a note on your hardware to `meta_*.json`. See [CONTRIBUTING.md](../CONTRIBUTING.md).

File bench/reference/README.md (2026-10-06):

# Benchmark reference solutions (frozen, v1)

These 16 files are the answer keys of Prompt-to-Bench-16: each is exactly the part its
prompt in `../tasks.yaml` describes, and the hidden checks and `../reference_stats.json`
were built from them. **Do not edit them** - every published score depends on them.

They test whether a model can follow a written specification. They are not the
recommended lab parts: the printable, lab-ready versions live in [`designs/`](../../designs/)
and differ where an audit found a better choice for real use (wider tube clearances,
safer gel-tank electrodes, standoffs for the stirrer magnets, and so on; see
`meta/audits/2026-10-06_mechanical_and_biological.md`).

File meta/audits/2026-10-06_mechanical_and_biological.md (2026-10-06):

# Mechanical and biological audit of the 16 printpaper designs

Scope: `designs/**/*.scad`, `bench/tasks.yaml`, `designs/README.md`, `tutorial/README.md`, and the safety and material statements in `README.md` (§2, §4, §8). No files were edited. Geometry was checked by reading each file and running `tools/scadreport.py` on all 16 (single renders). Facts were checked against manufacturer data where I could reach it.

Tags: **[ERROR]** means factually wrong, won't fit, or unsafe as written. **[RISK]** means a likely problem that deserves a parameter or note change. **[OK]** is used only where a claim needed checking and held up.

> **Read this before changing any parameter.** Each `.scad` file is also a benchmark reference solution. If you change a dimension, you must also change the matching prompt text and the hidden `checks` in `bench/tasks.yaml`, then rebuild the reference values (`build_refs.py`). Otherwise benchmark scores already computed will no longer match the reference. Note-only fixes (header comments, READMEs, tutorial) are safe to make at any time. Given the benchmark that is running, a reasonable plan is to fix the notes and safety text now, and save the dimension changes for a versioned "v2" design set.

## Key reference data used

| Item | Value | Source |
|---|---|---|
| Eppendorf Safe-Lock 1.5 mL tube | body Ø 10.8 / 10.7 mm, inner Ø 8.7 mm, cylinder ~20 mm, total length 37.8 mm below rim (38.9 mm overall), conical section ≈ 17.8 mm, wall 0.45 mm | [Eppendorf technical drawing](https://www.eppendorf.com/product-media/doc/en/140027_Technical-Data/Eppendorf_Consumables_Technical-data_Safe-Lock-Tube-15-mL_Safe-Lock-15-mL-technical-drawing.pdf) |
| Falcon 50 mL tube (352070) | O.D. 30 mm, length 115 mm | [Corning eCatalog 352070](https://ecatalog.corning.com/life-sciences/b2c/US/en/Liquid-Handling/Tubes,-Liquid-Handling/Centrifuge-Tubes/Falcon%C2%AE-Conical-Centrifuge-Tubes/p/352070) |
| 0.2 mL PCR tube | overall height 20.8 mm, inner Ø at top 5.40 mm, wall 0.29 mm (so OD ≈ 6.0 mm) | [i-labpro PC0201 spec](https://www.i-labpro.com/product/pc0201-f-n/) |
| Microscope slide (ISO 8037-1) | 76 × 26 mm, thickness 1.0 ± 0.05 mm | [Marienfeld](https://www.marienfeld-superior.com/microscope-slides-thickness-approx-1-mm.html), [Semadeni](https://eshop.semadeni.com/en/PRODUCTS/Life-science_-sampling-and-analysis/Microscopy-Accessories/DURAN_-microscope-slides_26x76_mm-1193.html) |
| 90 mm Petri dish | SPL 90 × 15 mm: internal Ø 85.90 mm. Some "90 mm" dishes have an 86 mm *base* OD (lid 90 mm). Glass 90 mm OD dishes: ID 85 mm | [SPL via ProLab](https://prolabcorp.com/spl-petri-dish-90-x-15mm-with-3-vents-lids-crystal-grade-polystyrene-sterile-sleeve-10-case-of-500/), [The Consumables Company](https://www.theconsumablescompany.com/90mm-petri-dish-single-vent-with-lid-polystyrene-ps-aseptic/), [Labnique](https://labnique.com/products/90mm-od-glass-petri-dish-with-lid-pack-of-10) |
| 6 mm D-shaft | Ø 6.0 mm, 4.5 mm flat-to-round, flat 12 mm long (Bourns PDB24 "F" shaft) | [Bourns PDB24](https://www.bourns.com/docs/product-datasheets/PDB24.pdf) |
| Lab stand rods | 12 mm (e.g. Eisco/LABZIO) and 12.7 mm (1/2") are both common | [Eisco rods](https://www.eiscolabs.com/collections/metal-bases-rods), [CP Lab Safety 12.7 mm](https://www.cplabsafety.com/lab-stand-base-with-59cm-long-rod-12-7mm-diameter-22cm/eis-abse12spl) |
| Barb stretch for silicone | 18-34 % over nominal ID | [Nordson Medical barb styles](https://fluid-components.nordsonmedical.com/files/fluid-components-nordsonmedical-com/Technical%20Information/Barb%20Information/barb-styles.pdf) |
| 80 mm fan | 71.5 mm hole pattern (paper cites SUNON); 4.3 mm holes; stock fan screws are 5 mm self-tapping | [Sanyo Denki tapping note](https://products.sanyodenki.com/info/sanace/en/technical_material/tapping.html), [Wikipedia: computer case screws](https://en.wikipedia.org/wiki/Computer_case_screws) |
| Mini agarose gel practice (Bio-Rad Mini-Sub Cell GT manual) | 7 × 7 / 7 × 10 cm gels; Mini-Sub combs 5.54 mm (8-well) or 2.59 mm (15-well) wide, 0.75-1.5 mm thick; pour agarose at 50-60 °C ("Hot agarose (>60 °C) may cause the tray to warp"); comb teeth 1-2 mm above the running surface; gel under 2-6 mm of buffer; Pt electrodes 0.25 mm; lid interlock; max buffer 40 °C | [Bio-Rad Sub-Cell GT manual](https://www.ubi.se/wp-content/uploads/2023/10/Wide-Mini-Sub-Cell-GT-Cell-BioRad.pdf) |
| ANSI/SLAS 1-2004 | 127.76 ± 0.25 × 85.48 ± 0.25 mm within 12.7 mm of the corners; "footprint must be continuous and uninterrupted"; corner radius 3.18 ± 1.6 mm. No chamfer is specified. | [ANSI SLAS 1-2004](https://www.slas.org/SLAS/assets/File/public/standards/ANSI_SLAS_1-2004_FootprintDimensions.pdf) |
| Prusa design guidance | accuracy "to at least 0.2 mm"; moving parts "at least 0.3 mm" | [Prusa KB](https://help.prusa3d.com/article/modeling-with-3d-printing-in-mind_164135) |
| PETG chemical resistance | good with ethanol; poor with acetone, phenol and chlorinated solvents (chloroform) | [chemicalresistance.org PETG](https://chemicalresistance.org/materials/petg/), [Plaskolite PETG](https://plaskolite.com/docs/default-source/tec/tec409_psk_chem_res_petg.pdf) |
| Alcohol disinfection | alcohols "lack sporicidal action" | [CDC disinfection guideline](https://www.cdc.gov/infection-control/hcp/disinfection-sterilization/chemical-disinfectants.html) |
| PETG HDT | 68 °C (ISO 75) | [Prusament PETG TDS](https://prusament.com/wp-content/uploads/2022/10/PETG_Prusament_TDS_2021_10_EN.pdf) |

---

## Benchware

### 1. `tube_rack_1p5ml.scad` (24 × 1.5 mL)
- **[OK] Tube diameter.** The 10.8 mm body figure matches Eppendorf (Ø 10.8 / 10.7 mm). The 25 mm blind hole leaves about 13 mm of tube plus the lid above the block. Tubes rest on their tips; that is fine.
- **[RISK] 11.2 mm holes leave only 0.2 mm per side, and the tutorial itself recommends more.** Vertical FDM holes usually print 0.1-0.2 mm undersize, so the real clearance will be about 0-0.1 mm per side. That is tight with 11.0 mm tubes from other brands, or with a little elephant's foot. The tutorial's own clearance table (Part 4) says a "tube in a rack hole" needs **0.3-0.5 mm per side**, and `designs/README.md` already uses `-D hole_d=11.6` as its CLI example.
  - *Fix:* `hole_d = 11.6`. Update the comment to "~0.4 mm clearance per side", and update the prompt and checks to match. If 11.2 is kept, change the tutorial's table row instead (see the internal-consistency section).
- **[OK] Printability.** Prints without supports; the web between holes is 4.8 mm.

### 2. `conical_rack_50ml.scad` (6 × 50 mL)
- **[RISK] The hole is barely larger than the tube.** Corning lists the Falcon 352070 at **O.D. 30 mm × 115 mm**. A 30.5 mm hole leaves 0.25 mm per side before FDM shrinkage. The header comment "~29-30 mm across" understates the fit risk.
  - *Fix:* `hole_d = 31.0` (0.5 mm per side). Change the comment to "50 mL Falcon is 30 mm O.D. (Corning 352070)".
- **[OK] Height.** With a 115 mm tube on its tip, the 66-70 mm plate leaves about 45 mm of tube and the cap above it. Tilt in the hole is under 1°.
- **[OK] Print orientation.** "No bridges, no supports" holds; scadreport finds no overhangs. Elephant's foot only affects the bed face (the top in use), which the clearance above absorbs.

### 3. `slide_drying_rack.scad`
- **[RISK] Slide size in the prompt and header.** Both say slides are "75 × 25 × 1 mm", but ISO 8037-1 is 76 × 26 mm and US 3"×1" slides are 76.2 × 25.4 mm. A blind 77 mm slot leaves only 0.4 mm per end, and slot ends print short.
  - *Fix:* `slot_len = 79`. Change the comment to "ISO 8037-1 slides are 76 × 26 × 1.0 mm".
- **[RISK] 1.6 mm slots print narrower.** At 0.45 mm extrusion width, a 1.6 mm slot often comes out about 1.3-1.4 mm, which leaves very little room for a 1.0-1.05 mm slide. The header's "check slot width with a real slide" is good advice.
  - *Fix:* `slot_w = 1.8`. The walls stay 1.7 mm thick (about 4 perimeters).
- **[RISK] Poor drying function for stained or smeared slides.** Each slide stands on its long edge with 10 mm of its 26 mm width inside a *blind* slot. That has three effects:
  - about 40 % of the face, including smear or section area, rubs on the slot walls;
  - liquid draining off the slide pools in the closed slot and wicks back up the ~0.3 mm gaps, so slides stay wet;
  - the 3.5 mm pitch leaves only 2.5 mm of air between slides.

  Commercial drying racks touch only the slide edges and let liquid drain.
  - *Fix:* `slot_depth = 4`, `slot_pitch = 5`, block Y = 60. Also make the slots drain, either through the block (cut to z = -eps) or with a 2 mm drain hole at each slot end. Add to the header: "Contact is edge-only; keep smears and sections above the block."
- **[OK] Printability.** Walls between slots are 1.9 mm (4 perimeters). No supports needed.

### 4. `pcr_tube_rack_sbs.scad` (96 × 0.2 mL, SBS)
- **[OK] Grid and footprint.** 127.76 × 85.48 mm, A1 at 14.38 / 11.24 mm and 9 mm pitch all match ANSI/SLAS 1-2004 and 4-2004.
- **[RISK] Hole size.** The tube OD is about 6.0 mm (5.40 mm ID + 2 × 0.29 mm wall). A 6.2 mm hole leaves 0.1 mm per side, so after FDM shrinkage, 96 holes will bind.
  - *Fix:* `hole_d = 6.4`. Change the comment to "0.2 mL tube OD ≈ 6.0 mm".
- **[ERROR] Claim: "Fits plate holders, plate magnets and plate lids."**
  - *Magnets:* a solid 20 mm block surrounds each tube's lower half, so the tubes cannot reach the posts or rings of a 96-well magnet stand.
  - *Lids:* the tubes (20.8 mm tall, plus caps) are as tall as the 20 mm rack, which is already higher than a standard plate (ANSI/SLAS 2: 14.35 mm). A plate lid cannot sit on it.
  - *Fix:* change the header to "Fits SBS plate carriers and holders. Not for magnet stands; plate lids will not fit over capped tubes."
- **[RISK] The chamfer and sharp corners break the footprint the header claims to follow.** ANSI/SLAS 1-2004 requires the base footprint to be "continuous and uninterrupted" and the corners to have a radius of 3.18 ± 1.6 mm. The 5 mm chamfer runs down to the bed, and the other three corners are sharp, so the part may not seat in a nest with radiused pockets. Real plates put the orientation chamfer on the upper skirt, not on the base flange.
  - *Fix:* start the chamfer at z = 6 mm, so the base stays a full rectangle, and round the four vertical edges with r = 3.18 mm. Alternatively, mark A1 by engraving it.
- **[RISK] The tubes may not hang in the holes.** A straight 6.0 mm tube in a 6.2-6.4 mm through-hole is held only if its cap or rim is wider than the hole. Otherwise it rests on the bench, flush with the top of the rack. That works, but say so: "Tubes rest on the bench through the holes."

## Tools

### 5. `gel_comb_10well.scad`
- **[OK] Material temperature.** PETG HDT is 68 °C, PLA's is about 55 °C, and Bio-Rad pours agarose at 50-60 °C. "PETG survives hot agarose better than PLA" is correct.
- **[RISK] The pouring temperature is not stated.** Students often pour agarose straight from the microwave at more than 80 °C, which will warp a 1.5 mm PETG comb. Bio-Rad itself warns: "Hot agarose (>60 °C) may cause the tray to warp."
  - *Fix:* add to the header: "Let the agarose cool to 50-60 °C before pouring (hand-warm flask)."
- **[RISK] Nothing sets how high the teeth sit, so wells may form through the gel.**
  - The comb is a flat 70 × 12 mm spine with 12 mm teeth and no shoulders.
  - Bio-Rad: "Comb should be placed 1 to 2 mm above the base of the running surface." Otherwise "sample wells cast through the gel" and the sample leaks out underneath.
  - A 70 mm spine also drops *inside* a 7 cm tray unless the tray has comb slots.
  - *Fix:* add a parameter note: `tooth_len` = (height of the spine's support above the tray floor) − 1.5 mm. Add two end tabs (for example 5 mm × 12 mm, spine 80 mm long) that rest on the tray walls.
- **[OK] Well dimensions.** 5.0 mm × 1.5 mm wells with 1.5 mm gaps are in line with Bio-Rad combs (5.54 mm 8-well, 2.59 mm 15-well; 0.75-1.5 mm thick).
- **[RISK] Smooth bed side.** The bed side is smooth only on a smooth PEI sheet; MK4s often ship with a satin or textured sheet. *Fix:* say "smoothest on a smooth PEI sheet".
- **[RISK] The comb does not fit the library's own gel tank.** The 10 teeth span 63.5 mm (spine 70 mm), but `mini_gel_tank.scad` is only 64 mm wide inside (see #16).

### 6. `micropestle_1p5ml.scad`
- **[OK] Geometry.**
  - The Eppendorf 1.5 mL tube is 8.7 mm inside at the top and has a conical section about 17.8 mm long.
  - The 8 mm handle clears it by 0.35 mm per side.
  - The pestle cone has a half-angle of 8.4°, a little narrower than the tube's cone (about 10-11°), so the rounded 3 mm tip reaches the bottom of the tube. "Matches the conical bottom" is a reasonable approximation.
- **[RISK] Tall, thin print.** It stands 63.5 mm tall on 50 mm² of bed contact, and the cone narrows to a 3 mm tip, so it may detach or wobble. *Fix:* add "use a 5 mm brim; print several at once so each layer has time to cool".
- **[RISK] Biological and chemical limits are missing.**
  - Commercial micropestles are polypropylene, autoclavable and certified RNase/DNase-free. A printed PLA or PETG pestle is none of these.
  - Its layer ridges hold tissue, so carry-over between samples is likely.
  - PETG resists phenol and chloroform poorly (TRIzol contains phenol).
  - PLA and PETG turn brittle in liquid nitrogen, so the 3 mm tip can snap off into the sample.
  - *Fix:* add to the header: "Single use. Not RNase-free or autoclavable. Do not use with phenol/chloroform (TRIzol) or acetone. If grinding under liquid nitrogen, expect brittle tips; grind gently."

### 7. `lab_funnel_60mm.scad`
- **[OK] Overhang.** The cone is 39.8° from vertical (25 mm of radius over 30 mm of height), so "below 45°" holds.
- **[RISK] "1.6 mm thick everywhere" is wrong for the cone.** The offset is horizontal, so the true wall thickness normal to the cone is 1.6 × cos 39.8° = **1.23 mm**. The prompt (`bench/tasks.yaml`) and the comment both say "1.6 mm thick everywhere".
  - *Fix:* reword to "1.6 mm wall measured horizontally (≈1.2 mm normal to the cone)". Alternatively, offset the inner cone by `wall / cos(atan(25/30))`, but that changes the checks.
- **[RISK] Unstable while printing.** The whole 60 mm funnel stands on the 10 mm spout ring (42 mm² of bed contact), so it can tip or detach late in the print. Printed rim-down instead, it is still support-free (the inside surface is 39.8° from vertical), and the bed contact rises to about 290 mm².
  - *Fix:* "Use a brim, or print it upside down (rim on the bed)."
- **[RISK] Chemical advice is too broad.** "PETG or PP for chemical resistance" will mislead: PETG is attacked by acetone, phenol and chloroform. Printing PP on an MK4 needs PP tape or a PP sheet.
  - *Fix:* "PETG: water, buffers, ethanol. Not for acetone, phenol or chloroform. PP needs a PP-tape bed."

### 8. `seed_sowing_template.scad`
- **[ERROR] "Fits inside a 90 mm dish" fails for common dishes.**
  - SPL 90 mm dishes are 85.90 mm inside (0.45 mm per side). Glass 90 mm dishes are 85 mm inside (zero clearance). Some 90 mm plastic dishes have an 86 mm base OD, so roughly 84.5 mm inside (interference).
  - Dish walls also have draft, so the opening narrows towards the floor, where the agar surface is.
  - *Fix:* `disc_d = 82`. The corner holes still stay inside, at 39.7 mm against a 41 mm rim. Update the prompt bbox and probes, and add "measure your dish's inside diameter at agar height".
- **[RISK] Placing it on the agar is an aseptic-technique problem.**
  - The template "lies on the agar", but the only disinfection given is "70 % ethanol". Alcohols "lack sporicidal action" (CDC).
  - Layer lines hold fungal and bacterial spores, and Arabidopsis plates on sucrose-MS medium are incubated for weeks, so spores will grow.
  - Lifting a 2 mm disc off soft agar also disturbs the seeds, and the disc has no tab to grip.
  - *Fix:* recommend using it **under** the dish as a sowing guide, seen through the clear base, which is standard practice. If it must touch agar, require "immerse in 70 % ethanol ≥ 10 min, air-dry in the flow hood, optionally UV both sides; single use". Add a 10 × 6 mm lift tab.
- **[OK] Hole layout.** A 9 mm grid with 3 mm holes is suitable for 49 Arabidopsis seeds (about 0.5 mm each).

## Quick fixes

### 9. `dshaft_knob_6mm.scad`
- **[OK] Shaft dimensions.** Bourns' 6 mm flatted shaft is Ø 6.0 with a 4.5 mm flat, so `shaft_d = 6.2` and `shaft_flat = 4.7` give about 0.1 mm per side. The D faces +X and the pointer groove also points to +X, consistent with the prompt.
- **[RISK] The flat may be shorter than the bore.** The bore is a D shape for its full 12 mm depth. Bourns flats are 12 mm long, but many pots and instruments have shorter flats (about 7-10 mm). The shaft's round section then meets the bore's flat near the mouth, and the knob cannot slide on fully.
  - *Fix:* make the bore round (Ø 6.2) for the bottom 5 mm and D-shaped above that. Note: "measure the length of the flat".
- **[RISK] Elephant's foot closes the bore mouth.** The bore opens on the bed face, where the first layer squishes inward, so the shaft won't start.
  - *Fix:* add a 0.5 mm × 45° chamfer at the bore mouth, or "enable elephant-foot compensation".
- **[RISK] Not every stirrer shaft is 6 mm.** Many US instruments use 1/4" (6.35 mm) shafts. The header says "hotplates, stirrers, power supplies" without asking the user to measure.
  - *Fix:* "Measure the shaft: 6.0 mm metric or 6.35 mm (1/4") imperial; set `shaft_d` = measured + 0.2."
- **[OK] Printability.** The bore ceiling is a trivial 6.2 mm bridge.

### 10. `pcr_tube_adapter.scad`
- **[ERROR] Its geometry is that of a microcentrifuge adapter, but nothing says not to spin it.** The name "0.2 mL-in-1.5 mL tube adapter" and its 10.8 mm OD sleeve match exactly what a student would drop into a 1.5 mL rotor bore. That contradicts the paper's §8 and the tutorial ("never print ... tube adapters for a commercial centrifuge").
  - *Fix:* add to the header and to `designs/README.md`: "For racks only. NEVER use in a centrifuge rotor."
- **[RISK] The tube may fall through.** The bore is a straight 6.2 mm through-hole and the tube OD is about 6.0 mm. Unless the cap rim catches, the 20.8 mm tube slides to the floor of the 25 mm rack hole and sits about 4 mm below the collar, where it is hard to retrieve.
  - *Fix:* make the bore blind, 15 mm deep, with a 1.5 mm floor. Printed collar-down, the floor is a trivial 6 mm bridge.
- **[RISK] The heat-block advice misleads.** "Not for heat blocks unless printed in a high-temperature material" implies that some FDM material would be fine. PCR blocks reach 95 °C, which is above the HDT of PETG (68 °C) and close to that of ASA/PC. A plastic sleeve also insulates the tube, so it would not reach the set temperature.
  - *Fix:* "Not for heat blocks or thermal cyclers in any printed material: plastic insulates the tube and softens."
- **[OK] Fit and printability.** A 10.8 mm body in an 11.2 mm hole fits; the wall is 2.3 mm; no overhangs.

### 11. `hose_barb_reducer_8_5.scad`
- **[OK] Barb sizing.** Stretch is 9.5/8 = 19 % and 6.5/5 = 30 %, both within the 18-34 % Nordson recommends for silicone. Barbs face the right way on both ends, and both lead-in diameters (7.5 and 5.0 mm) are no larger than the tubing ID.
- **[RISK] Weak where it is most loaded.**
  - Printed upright, the layer lines run across the axis, so bending or pulling the tubing breaks the part at the sharp steps beside the collar (z = 20 and z = 25).
  - The tip of the 5 mm side is only 1.0 mm thick (5.0 OD, 3.0 bore), so it gets just two perimeters.
  - The part is 41 mm tall on 37 mm² of bed contact.
  - *Fix:* `bore_d = 2.5` (1.25 mm tip wall). Add a small fillet or 45° cone where the barbs meet the collar, and "use a brim". Add to the header: "Not for lines under tension or bending; not for pressurised or biohazard lines."
- **[OK] Flow and overhangs.** The 3 mm bore limits flow to about 36 % of a 5 mm bore. That is acceptable for the stated use and worth one line in the header. The flat overhangs scadreport flags at z = 20 and z = 33 are 0.75-1.25 mm ledges and print fine.

### 12. `rod_tubing_clip.scad`
- **[RISK] Rod size.** Twelve millimetres is at least as common for stands as 12.7 mm (Eisco and LABZIO rods are 12 mm). On a 12 mm rod, a 12.7 mm ring has 0.35 mm per side of play and slides down the rod. Even on a 12.7 mm rod, a ring with zero clearance holds only by friction.
  - *Fix:* add a comment: "rod_id = measured rod Ø − 0.2 mm for grip (12 mm and 12.7 mm rods are both common)".
- **[OK] Snap fit.** A 10 mm opening on a 12.7 mm rod means each arm moves 1.35 mm. That is about 2 % strain in a 3 mm wall, fine in PETG and marginal in PLA, so the header's choice of PETG is right. The ring is printed flat, so the bending is within layers.
- **[RISK] The tubing size is unstated.** The 6 mm ring fits only 6 mm OD tubing (for example 4 × 6 mm or 1/8" × 1/4"). The library's own 8 mm and 5 mm ID silicone tubing (about 11 mm and 8 mm OD) will not fit.
  - *Fix:* change the comment to "tube_id = tubing OD".

## Full hardware

### 13. `stirrer_fan_housing.scad`
- **[OK] Fan holes.** The 71.5 mm pattern is correct for 80 mm fans. 4.5 mm holes take M4 screws with nuts. Stock fan screws (about 5 mm self-tapping) will not pass, which is acceptable because the header says M4.
- **[ERROR] The magnets will hit the top plate.** The header says to glue the magnets to the hub and screw the fan *directly* under the top plate. The hub is roughly flush with the fan frame, so magnets (usually 2-5 mm thick) stick up and rub on the 2 mm plate. Every DIY build guide uses spacers "higher than the profile of the fan with the magnets glued on".
  - *Fix:* add four standoffs of magnet height + 1 mm at the hole positions, for example cylinders d = 8 mm, h = 4 mm around each hole. Or state: "use 4 mm spacers or nuts on M4 × 35 screws". Also add: "glue the two magnets with opposite poles facing up, symmetric about the hub".
- **[RISK] Screw heads stand on the stirring surface.** The M4 heads sit proud of the top plate, where the beaker stands.
  - *Fix:* countersink the holes from the bed face (90°, Ø 8.4 mm). Printed bed-down, a 45° countersink is printable.
- **[OK] Plate stiffness.** A 2 mm plate spanning 71.5 mm sags about 0.4 mm under a 1 kg point load, which is acceptable.

### 14. `nema17_motor_bracket.scad`
- **[OK] Motor interface.** The 31 mm M3 pattern and 22 mm pilot are correct (Oriental Motor). 3.4 and 4.5 mm are the ISO 273 medium clearances for M3 and M4. All screw heads clear the gussets and base.
- **[RISK] "Prints without supports" is optimistic for the 23 mm horizontal hole.** scadreport reports 144 mm² steeper than 45° and a flat area at z = 39.5. That is the crown of the hole, a bridge about 16 mm wide. The crown typically sags 0.3-0.5 mm, which uses up most of the 0.5 mm radial clearance around the 22 mm pilot.
  - *Fix:* use a teardrop or flat-topped hole (flat at z = boss_z + 11.5, 45° sides), or set `boss_d = 23.5`. Add "check that the pilot fits" to the header.
- **[RISK] It must be screwed down.** The motor (about 0.3 kg) hangs behind the plate (−Y), outside the base footprint, so an unscrewed bracket tips backwards. *Fix:* add "screw the base down before mounting the motor".

### 15. `enclosure_box_and_lid.scad`
- **[OK] Lip fit.** 65.6 mm against a 66 mm opening is 0.2 mm per side, as stated.
- **[RISK] "Push fit" or "sliding"?** The tutorial classes 0.2-0.3 mm per side as a *sliding* fit ("a lid lip in a box"), not a push fit. Depending on the printer, the lid may simply fall off.
  - *Fix:* call it a "slip-fit lid". Suggest `clearance = 0.1` for friction, or tape.
- **[RISK] The example board does not fit.** The prompt suggests an "Arduino-based temperature logger", but an Arduino Uno is 68.6 × 53.4 mm and the box is 66 × 46 mm inside. There are also no cable, USB or vent openings.
  - *Fix:* change the prompt and header to "Arduino Nano-based". Add the note "add a cable hole (e.g. 6 mm) before printing".

### 16. `mini_gel_tank.scad`
- **[ERROR] The electrodes sit above a normal buffer level.**
  - The platform top is at z = 13. A typical 5 mm gel (on a tray) has its top at about z = 18-21.
  - Bio-Rad specifies 2-6 mm of buffer over the gel, so the buffer level is about z = 20-27. The wire holes are at **z = 30**, so the electrodes would not be submerged.
  - Filling to cover them means about 10 mm of buffer over the gel: more current, more heat, slower runs.
  - The wire also enters along X at a single point (y = 0), so it is not a wire spanning the chamber width. That gives a non-uniform field and curved ("smiling") bands.
  - *Fix:* electrodes must run across each buffer chamber along Y, near the floor. Do one of the following:
    1. move the holes into the side walls, along Y, at x = ±52, `wire_z = 5`, and seal them with silicone or epoxy; or
    2 (safer against leaks). remove the holes, run the wires over the rim into floor grooves, and bring them to shrouded 4 mm sockets.

    Make `wire_d` match the wire: Bio-Rad uses 0.25 mm Pt, so a 2 mm hole is a leak path.
- **[ERROR] A live conductor would be exposed outside the tank.** As designed, the bare electrode wire leaves through the end walls at 50-150 V DC, with no insulation and no shroud. The header and README rightly demand "a closed lid with an interlock", but the design includes neither lid nor interlock. Under IEC 61010-1, more than 35 V DC in wet locations counts as hazardous live (clause 6.3, from memory).
  - *Fix:* add to the header: "Lid and interlock are NOT included in this file. Do not connect a power supply until a lid that carries the shrouded connectors (so removing it breaks the circuit) is built." Keep electrode wire inside the tank and out of reach.
- **[RISK] Gel width.** Inside, the tank is 114 × 64 mm. Standard mini-gel trays are 7 cm wide (Bio-Rad 7 × 7 or 7 × 10 cm) and do not fit, and neither does the library's own 70 mm comb (#5).
  - *Fix:* `outer = [130, 90, 40]` (84 mm inside), `platform_len = 75`.
- **[RISK] Electrode material.** Stainless steel works as a cathode, but as an anode it corrodes. It browns the buffer, and the released metal ions damage DNA and RNA ([diybio thread](https://groups.google.com/g/diybio/c/GWTrmC6vMfc), [ResearchGate orthodontic-wire study](https://www.researchgate.net/publication/391423051_Using_Orthodontic_Wire_electrodes_in_Gel_Electrophoresis_Device)).
  - *Fix:* "platinum (or graphite) for the anode; stainless steel only as the cathode, and replace it if the buffer discolours".
- **[OK] Print settings.** PETG with 4+ perimeters and a water leak test is good advice. Bio-Rad limits buffer to 40 °C, and PETG is fine there.

---

## Cross-cutting and internal-consistency findings

- **[RISK] The tutorial's clearance table contradicts its first exercise.** Part 4 says "loose (drops in) 0.3-0.5 mm per side, e.g. tube in a rack hole". Parts 2-3 use 11.2 mm for a 10.8 mm tube (0.2 mm per side) and call it "a little extra room". Choose one; I recommend `hole_d = 11.6` everywhere. Changing this alters the tutorial prompt *and* the benchmark task, so it is a v2 change. The safe interim note is: "0.2 mm per side is the minimum; if tubes stick, go to 11.6 mm."
- **[RISK] Table 1 print times use different settings from the headers.** The estimates come from the stock 0.20 mm SPEED PLA profile (`tools/slice_library.py`). Several headers prescribe slower settings: hose barb 0.12 mm and 100 % infill; pestle 0.12-0.15 mm and 100 %; comb 0.15 mm and 100 %; clip 100 %; bracket 5 perimeters and 30 % infill; knob 0.15 mm and 4 perimeters. Several also recommend PETG.
  - *Fix:* add to the Table 1 caption: "Default profile, not the per-part settings in the file headers; parts with 100 % infill or finer layers take longer."
  - The totals check out: 31.64 h and 482.9 g.
- **[RISK] "Each ... prints without supports" (README §2).** This holds except for the bracket's 16 mm-wide crown bridge (#14) and the 0.75-1.25 mm ledges on the barb collar. Say "without supports (the bracket's motor hole bridges its crown)".
- **[RISK] README §8: "PETG, PP and PC deform at 121 °C."** This is true of *printed* parts in the cited studies, but molded PP labware is routinely autoclaved: Corning lists Falcon PP tubes as "stable from -80 °C to +121 °C", and Eppendorf PP PCR tubes are autoclavable at 121 °C. Readers may conclude that PP tubes cannot be autoclaved. *Fix:* "Printed PETG, PP and PC parts deformed at 121 °C in tests (...)."
- **[OK] Tutorial dimensions.** 10.8 mm for a 1.5 mL tube, 71.5 mm for 80 mm fans, 31 mm and 22 mm for NEMA 17, Prusa's 0.2 mm accuracy and 0.3 mm for moving parts, PETG HDT 68 °C, PLA softening at 55-60 °C, 0.45 mm perimeters and the 45° overhang rule are all consistent with sources.

## Tutorial and paper statements on biology and safety

- **[RISK] Tutorial Part 7, cleaning.** "Wiping with 70 % ethanol ... is fine" is correct as *disinfection*. Nowhere does the tutorial say this is not sterilisation, and alcohols are not sporicidal (CDC). That matters for anything that touches agar or cultures, such as the seed template.
  - *Fix:* add "Ethanol disinfects but does not sterilise (it does not kill spores). For anything that touches media or cultures: soak ≥ 10 min in 70 % ethanol, dry in the hood, single use, or use the part outside the dish."
- **[RISK] Tutorial Part 7, materials table.** The table omits two lab-relevant limits:
  - agarose should be cooled to 50-60 °C before it touches PLA or PETG combs and trays;
  - PETG and PLA are attacked by phenol, chloroform (TRIzol and phenol-chloroform extractions) and acetone.
  - *Fix:* add both to the "Avoid" column.
- **[RISK] Tutorial "Never print" list vs. the library.** The list says "tube adapters for a commercial centrifuge", yet the library ships a sleeve sized exactly for a 1.5 mL rotor bore (#10). Add "for racks only, never in a centrifuge" to that design and to `designs/README.md`.
- **[RISK] Tutorial Exercise 5 (fan stirrer).** It never mentions magnet clearance or polarity, or that neodymium magnets are dangerous if swallowed or pinched.
  - *Fix:* "Leave spacers so the magnets clear the top plate; glue them with opposite poles up; keep loose neodymium magnets away from children and pacemakers."
- **[OK] Paper §8 and tutorial Part 6 on electricity.** "Keep electronics low-voltage, certified supplies, no mains" is appropriate. The gel-tank voltage range of 50-150 V DC is realistic: Bio-Rad runs mini gels at 75 V. But see #16: the shipped tank design itself exposes live wire and has no lid, so the warning needs "lid not included" next to it.
- **[OK] Paper §4 and §8 on materials.** No autoclaving of PLA (Neijhoft), PETG HDT 68 °C, brief ethanol, isopropanol or hypochlorite wipes, ventilation, and the centrifuge exclusion are all accurate.

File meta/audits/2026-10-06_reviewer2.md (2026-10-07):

# Adversarial review ("Reviewer 2"): code, numbers, designs and prose

Snapshot: HEAD `0e77486` plus working tree, 6 Oct 2026 ~18:00, while the Qwen3.5 4B local run was still writing `bench/results/main/`. Three reviewers (harness code, every number against the data, designs) ran in parallel with one prose pass; all were report-only, and fixes were applied afterwards. Like the earlier audits, this was done by Claude, which also wrote the work, so it is not independent review.

## Fixed

**Checker (could let wrong parts pass)**
- Two `line` checks on the gel comb had the same name (`line z=0.75`), and results are keyed by name, so the spine check overwrote the 10-teeth check. A 9-tooth comb and a comb with 0.5 mm gaps both passed. Repeated names are now numbered (`checks.py`), and comb probes pin the tooth pitch.
- A one-groove micropestle and a knob with a 7 mm bore (instead of 12) passed. Added slices at z = 15, 20, 25 (pestle) and z = 11.5 (knob).
- An arc with no material counted as one gap. It now fails.
- These four wrong parts are now in `bench/mutants/`. `build_refs.py` requires them to fail.
- `build_refs.py` no longer overwrites the frozen `reference_stats.json`. It compares against it unless `--write` is passed.
- Re-checking all hosted-model and Swahili attempts with the new checks changed no verdict, only partial scores.

**Data and analysis**
- The Swahili code files of `lang-claude` had no language suffix, so `rescore.py` and `analyze.py` never found them. They have been renamed `*_sw_a*` and re-checked.
- After the funnel rescore, Sonnet's first attempt passed, but the repair attempt that followed was still counted ("0/1 same code", "0/17 attempts"). `analyze.py` now drops attempts after the first pass.
- "Geometry as a value" was counted on LFM2.5's unfenced reasoning prose. It now counts only extracted code blocks.
- `analyze.py` now computes the language McNemar tests. It also takes `--runs`, so a contributor's own run can be analysed, and dead figure code was removed.
- `run_bench.py` records the decisive OpenSCAD message when there are more than 10, and keeps "mesh analysis failed" in the record. Its dirty-tree flag no longer fires on results and logs.
- `rescore.py` reports failed re-renders and pass-to-fail flips instead of silently keeping old verdicts.
- `slice_library.py` dropped the seconds from print times, so the total was 32.8 h instead of 33.0 h. After the design fixes below it is 33.7 h, 508 g.
- `pull_models.sh` was missing `qwen2.5:1.5b`, and the README reproduce steps had no pull step. `make lang` ran a local language run that the paper says was not done.

**Designs**
- The seed template's lift tab made it 86.7 mm long, so it no longer fit inside a 90 mm dish. The tab is now a tweezer slot inside the disc.
- In the slide rack, slides could lean about 11° in their slots and touch their neighbours. The slots are now 6 mm deep at an 8 mm pitch, the block grows with the slot count, and drain channels run under the block.
- The clearance coupon covered only 0-0.25 mm per side, which cannot find the 0.3-0.5 mm "loose" fit the paper recommends. It now goes to +1.0 mm on the diameter, the plate follows `pitch`, and the peg is chamfered against elephant's foot. The print time is about 35 min, not 15.
- The funnel's true-wall fix had left a 0.5 mm lip and a 5.8 mm throat at the spout. The bore now continues into the cone.
- Hose barb: the header said 3 mm bore against the actual 2.5 mm. There was a flat 1.25 mm overhang under the collar, now a 45° cone. The advice no longer suggests it for biological aspiration.
- Rod clip: the default gave no grip on a 1/2" rod. The snap openings and ring spacing now follow the measured diameters.
- The tube and 50 mL racks had fixed block sizes. Following the tutorial's "change `cols`" instruction would have cut holes through the side. The blocks are now computed from the grid.
- Gel tank: added "+"/"−" polarity marks, and dropped the claim that the comb fits the tank.
- The adapter, knob, tube-rack and seed headers were corrected.
- Every design described its parameters in trailing comments, which the Customizer ignores, and decimal values stepped by 1 mm. Each description is now on the line above its parameter, and decimal values have a step.

**Paper and docs**
- No user study backs "reliable for people without CAD training" or "a practical way for a biologist without CAD training". These claims are reworded, and the gap is added to §9.
- §3 said "two features of the loop matter more than the choice of model". The results show that the model choice decides everything here.
- Corrected: the McNemar p-values (0.375, 0.125), Sonnet's 3.5-11.5 s, the truncation counts (complete runs only), the bridge and support claims, and the slip-fit title.
- "Failures differed between languages, as sampling noise would produce" was wrong. The NEMA 17 bracket failed in all three translations with the same check.
- The audits are no longer called "independent".
- The tutorial overstated feedback ("helped the hosted models fix most…") and "tips that make small models work better" (untested).
- Removed filler: slogans, "literally", "the single best investment", "That is all OpenSCAD is", "We hope others will", and the opener of §8.

## Not fixed (deliberately or not yet)

- **Local run rescored after the Qwen3.5 4B run finished** (19:31): 24 partial scores changed, no verdict. LFM2.5's attempts were extracted before unclosed `<think>` blocks were stripped; rescoring does not re-extract code, so that would need a `--reextract` mode.
- **Harness kept frozen while runs remain:** `scadreport` reports circular islands by bounding length but holes by area-equivalent diameter, and `repeating()` is not anchored to the end of the reply. Changing either would change what models see mid-study.
- The resume key ignores `num_predict`, `think` and temperature. This is documented in `bench/README.md`.
- `build_refs.py` tests one composite transform, not all eight symmetries. The eight-symmetry search in `checks.py` was reviewed and is correct.
- No canary string in the tasks.
- `meta/BUILD_LOG.md`, `bench/logs/*.log`, `bench/results/main/` and `summary.csv` are untracked, yet the paper links or relies on them. Commit them (after reviewing the build log's redaction) once the run ends.

## Follow-up, 7 Oct 2026: edge cases and hardening (v0.2.0)

**Harness.** About 75 new tests in `bench/test_harness.py` cover:
- extraction: fence variants, CRLF, `<think>` blocks, empty, `None`, unicode and 2 MB replies;
- rendering: missing imports, timeouts, non-manifold or disjoint parts, parts below z = 0, paths with spaces, non-UTF-8 OpenSCAD output;
- the checker: degenerate, empty or NaN meshes against all 16 tasks;
- a fake Ollama server: not running, model missing, a non-Ollama answer, an error mid-stream;
- argument errors, damaged or foreign result lines, and missing tools.

Fixes:
- Crashes on non-UTF-8 OpenSCAD output and on surrogate or `None` replies.
- A missing Claude CLI used to retry for about 10 min per task; it is now refused before the run starts.
- A non-Ollama answer on the port used to wait 300 s; it now fails at once.
- Unknown `--tasks` and impossible arguments ran nothing or crashed. They are now refused before the run starts.
- A quadratic-time fence regex.
- A stale STL could be reused after a failed render.
- Clean errors when OpenSCAD or PrusaSlicer is missing.

Non-regression:
- 0 verdict or score changes when all 290 saved conversations are rescored;
- identical extraction on all 705 saved replies;
- identical scadreport output on 125 parts;
- `reference_stats.json` and the `analyze.py` output unchanged.

**Designs.**
- Every design now stops with an `assert()` message when its parameters would make a broken or unsafe part, such as overlapping holes, a floor or wall under 0.8 mm, a gel-tank groove that could leak, or a bore that breaks through.
- `tools/check_designs.py` (`make designs`) renders each design with its defaults and with 39 edge-case parameter sets.
- This found a real defect: the D-shaft knob rendered as 41 bodies and was not watertight, because the round mouth bore and the D bore had coincident faces. Fixed by rotating the round section half a facet.

**Build log.** An earlier session's grep command had put a bare e-mail local part and a fragment of a private string into `meta/BUILD_LOG.md`. `build_log.py` now redacts bare `user@` strings, and the log was re-scanned before release.

**Found, not fixed** (a fix would change how the remaining Qwen3.5 9B run is scored):
- An Ollama stream that ends without `done` is scored as the model's reply instead of being retried. One record is affected: granite4.2:3b, stirrer housing, attempt 3, which was a fail either way.
- `~~~` fences and a code block nested inside another block are not extracted. No saved reply has either.
- A missing local model is only detected when the run reaches it.

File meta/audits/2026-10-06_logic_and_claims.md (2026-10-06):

# Audit of logic, methods and claims: printpaper (Prompt to Bench)

Snapshot audited: working tree at HEAD `0498617` plus untracked `bench/results/main/` (202 records, read 6 Oct 2026 ~17:40). Qwen3.5 4B (8/16 tasks) and Qwen3.5 9B (2/16) are **incomplete**, so every number for them is provisional.
Data sources: `bench/results/{main,main-claude,lang-claude}/results.jsonl`, `meta_*.json`, `bench/logs/*.log`, the saved `.scad`/`.reply.txt` files, and `analyze.py --no-readme` output.

**Caveat:** `refs_research.md` is **not present** at `/tmp/claude-1000/-home-seb-printpaper/20fd6f84-13bd-4473-9e16-35a18c47f756/scratchpad/` (the directory holds only `rack.scad`). So I could not check citations against the verified notes. Citation findings below cover only the places where the sentence and the cited work don't logically match. Every literature number (ITU, Microsoft, The Stack sizes, Nyamsuren, Dong, McNair 8.18%, Li 2025) still needs that check.

---

## 0. What the current data supports (headline)

| | n | pass ≤3 | pass 1st | renders 1st | renders any | mean best item-score |
|---|---|---|---|---|---|---|
| Claude Sonnet 5.5 | 16 | 16 | 15 | 16 | 16 | 1.00 |
| Claude Haiku 4.5 | 16 | 14 | 11 | 15 | 16 | 0.99 |
| 12 complete local models | 192 | **0** | 0 | 0-12 per model | 0-12 per model | 0.00-0.36 |
| Qwen3.5 4B / 9B (partial) | 8 / 2 | 0 / 0 | 0 / 0 | 1 / 1 | 1 / 1 | 0.03 / 0.44 |

What the data supports:
- **No tested local model passed any task**: 0/202 conversations. Every complete local model is at 0/16 (Wilson 95% upper bound 19%). Under p = 0.5, P(0/16) = 1.5e-5. So each complete model falls clearly short of the pre-set "half of 16" bar, *under this protocol*: Q4_K_M, thinking off, 2,048-token cap, T = 0.2, one sample, at most three oracle-triggered attempts.
- **Both hosted models are near ceiling.** Haiku 14/16 and Sonnet 16/16 are not distinguishable (Fisher p = 0.48; first try 11/16 vs 15/16, p = 0.17).
- **Language (Haiku only, one sample):** en 14, es 13, hi 12, sw 11. Paired exact McNemar p = 1.00, 0.62 and 0.38. First-try sw 6 vs en 11 (p = 0.125). There is **no detectable effect**.
- **Where local models fail** (first attempt): mostly parse errors. Much of that comes from treating geometry as values (`block = cube(...)`, `holes = for (...)`): 15/16 first files for Qwen2.5-Coder 7B, 14/16 for 1.5B, 11/16 for 3B. Four models mostly ran out of tokens (see #2).
- **Feedback did nothing for several small models.** They returned byte-identical code after every repair message: Qwen2.5-Coder 1.5B 32/32, 7B 32/32, 3B 31/32, Qwen2.5 1.5B 27/32, Qwen2.5-Coder 0.5B 24/32.

What the paper must NOT claim (details in the findings):
- any "minimal viable" local model;
- that small or local models *cannot* do this in general (the result is protocol-bound: thinking off, cap, one sample);
- any language effect;
- a Haiku-vs-Sonnet ranking;
- that `scadreport` feedback "makes small models usable";
- that "printable" means a valid printable part;
- that timings are clean;
- that Claude ran at T = 0.2;
- that the 16 designs are physically "tested".

---

## Findings

### Errors in data or code that change scores or statements

**1. [ERROR] The funnel task fails a valid reading of its own prompt, and the reference violates the spec.**
- The prompt says: "The wall is 1.6 mm thick everywhere" (`bench/tasks.yaml:155`).
- The reference `designs/tools/lab_funnel_60mm.scad` offsets the cone *horizontally* by `wall`. On a 39.8° cone that gives a wall only 1.6·cos 39.8° = **1.23 mm** thick when measured perpendicular to the surface.
- Sonnet's first attempt (`main-claude/code/claude_claude-sonnet-5-5/lab_funnel_60mm_s0_a0.scad`) used a perpendicular 1.6 mm wall ("measured perpendicular to the surface"). It passed every dimensional check and failed only `volume 7298 vs ref 5893 (±15%)` (+24%).
- The diameter tolerances (`hole_d [31.4, 0.8]`, `[55.5, 0.9]`) were evidently widened to admit both readings. The volume tolerance was not.
- **Fix (no rerun needed):** set `volume: {rel_tol: 0.35}` for `lab_funnel_60mm`, or drop the volume check (the probes and diameters already constrain the part). Then rescore the saved `.scad` files. Sonnet's first-try count becomes 16/16.
- Also add to the prompt for future versions: "(1.6 mm measured horizontally)". In §5.2, report that one false negative was found and corrected.

**2. [ERROR] "Thinking is switched off" (README:196) is false for LFM2.5, and many local failures are really truncation.**
- LFM2.5 has the `thinking` capability, and `think: false` was sent (`think=False` is recorded). Even so, **48/48 LFM2.5 replies contain `<think>` reasoning** in the content. 40/48 hit the 2,048-token cap.
- Because the `<think>` block never closed, 26 attempts were extracted as "bare" prose (whole reasoning text fed to OpenSCAD) and 10 as "no code".
- Attempts that hit the cap:

  | Model | Attempts at the 2,048 cap |
  |---|---|
  | Granite 4.2 3B | 37/48 |
  | Qwen3.5 2B | 29/48 (13 more stopped as repetition) |
  | Qwen3.5 4B (partial) | 19/24 |
  | Qwen2.5-Coder 0.5B | 4/48 (23 more stopped as repetition) |

- Spot checks (e.g. `qwen3.5_4b…/tube_rack_1p5ml_s0_a0.reply.txt`, `granite4.2_3b/tube_rack_1p5ml_s0_a0.reply.txt`) show reasoning written into `//` comments until the cap. That supports the §9 statement, but it applies to Granite too, not only Qwen3.5.
- **Fix the README:196 text** to: "'Thinking' was requested off for every model that supports it. Qwen3.5 and Granite 4.2 then reasoned inside code comments, and LFM2.5 ignored the switch and emitted `<think>` reasoning in all 48 replies. For these four models most replies (60-90%) hit the 2,048-token cap, so their score measures 'did not finish within 2,048 tokens' as much as design ability."
- Update §9 "Settings" the same way.

**3. [ERROR] `failure_stage` (analyze.py:105-119) labels truncated output as "syntax error" or "no code".**
- In Table 5, LFM2.5 shows "5 no code / 11 syntax error". All 16 were reasoning cut off at the cap.
- Most first-attempt "syntax errors" are truncations: Qwen3.5 2B 15/16, Granite 12/16, Qwen3.5 4B 7/7.
- **Fix** (insert before the render check):
  ```python
  if a.get("usage", {}).get("done_reason") in ("length", "repetition") and \
     not a.get("render", {}).get("ok"):
      return "truncated"
  ```
- Add `"truncated"` to `stages` in `table_failures` (analyze.py:381), and add "truncated (hit the token cap or looped)" to the Table 5 caption.

**4. [ERROR] "Models ran one at a time, so the timings are clean" (README:198; also `run_main_local.sh:2`) is false.**
- `main-claude` ran 15:35-16:13 and `lang-claude` ran 16:02-17:48 on 5 Oct. Both render and check every attempt with OpenSCAD and trimesh on the same CPU.
- The retained Qwen2.5-Coder 7B records (16:09-17:04) overlap the language run.
- The Haiku English run (to 16:11) and the Haiku Spanish run (from 16:03) overlapped each other.
- The author also reports other CPU work during some runs.
- **Fix:** "Local models ran one at a time, but some runs overlapped other work on the same laptop (for example, the Qwen2.5-Coder 7B run overlapped the hosted language run, whose rendering and checking use the CPU). Timings are indicative to within roughly ±20%, not clean benchmarks."
- Better still, re-time one task per model in isolation (cheap; tokens/s only).

**5. [ERROR] The token-cap protocol is not as stated (README:195, bench/README.md:37).**
- `meta_20261005_154725.json` shows `num_predict: 1024` for the first local pass.
- The cap was raised to 2,048 in commit `1ffe43e` (20:27). That was *after* seeing truncation, so it was a post-hoc protocol change.
- Qwen2.5-Coder 1.5B, Gemma 4 E4B and Ministral 3 were rerun at 2,048 and their 1,024-cap data dropped.
- **Qwen2.5-Coder 7B and 3B were kept at the 1,024 cap.** Their longest replies were 723 and 574 tokens, so the cap never bound, and with fixed seeds the outputs would be identical.
- **Fix:** add "Qwen2.5-Coder 7B and 3B ran with an earlier 1,024-token cap. None of their replies exceeded 723 tokens, so the cap never applied. All other local models ran with 2,048. We raised the cap after a first pass showed Gemma 4 E4B and others being cut off."

**6. [ERROR] The hosted-model token figures (README:197) are wrong.**

| Model | Paper says | Data shows |
|---|---|---|
| Haiku 4.5, main run | 10,000-16,000 output tokens per reply | 4,100-23,456 per reply, median ≈ 10,000 |
| Haiku 4.5, language runs | — | 1,904-26,126 output tokens (thinking 1,325-24,801) |
| Sonnet 5.5 | 400-1,200 tokens in 4-17 s | 320-1,430 tokens (median 668); 3.5-11.5 s per reply; 4-17 s per task |

- **Fix:** "Claude Haiku 4.5 used extended thinking (median about 10,000 output tokens per reply, range 4,100-23,500), while Claude Sonnet 5.5 answered directly (320-1,430 tokens, 4-12 s per reply)."
- "A correct solution needs about 400-700 tokens" (README:195) should instead cite Sonnet's passing replies: "Sonnet's passing replies used 320-1,430 tokens."

**7. [ERROR] Claude did not run at temperature 0.2, but the metadata says it did.**
- `ClaudeCLI` ignores `temperature`. The Claude CLI has no temperature flag, so Claude used the API default (1.0 with thinking).
- `main-claude/meta_*.json` and `lang-claude/meta_*.json` nonetheless record `"temperature": 0.2` (and `num_predict`).
- README:370 ("one sample per model at a low temperature") is therefore false for the hosted reference, and Claude's run-to-run variance is larger.
- **Fix the README:** add to the hosted bullet: "Claude ran at the API's default temperature (it cannot be set from the CLI), with no seed, so its results vary more between runs than the local models'."
- **Fix the code:** in `main()`, write `meta["args"]["temperature"] = None` (and `num_predict`) for `claude:` models.

**8. [ERROR] Design count (README:134).** It says "two of our designs (the 50 mL rack and the stirrer housing) are modelled that way [upside down]". At least **four** are: the 0.2 mL adapter ("Print it upside down", tasks.yaml:222) and the enclosure lid ("printed upside down", tasks.yaml:359) too. Table 2 itself lists "upside-down printing" for the adapter.
- **Fix:** "four of our designs (the 50 mL rack, the tube adapter, the enclosure lid and the stirrer housing) are modelled that way."

**9. [ERROR] Tolerance range (README:177).**
- The paper says "Dimensional tolerances are 0.25-0.6 mm". The actual absolute tolerances in tasks.yaml run **0.15-0.9 mm**: enclosure lip `island_tol 0.15`; funnel `hole_d` 0.8/0.9; most are 0.3-0.5.
- There are also relative ones: volume 5-15%, material area 4-5%, D-bore area 12%.
- The appeal to print accuracy (Li 2025) is a category error: the checks measure CAD, which has no print error.
- **Fix:** "Absolute tolerances are 0.15-0.9 mm (most 0.3-0.5 mm, tighter for the 0.2 mm clearance fit, looser where the prompt allows two readings), plus 4-15% on areas and volumes. They are set to accept every reading of the prompt we consider correct, not to mimic print accuracy."

**10. [ERROR] `scadreport` description (README:113).** It says it "slices the part horizontally at every distinct height". The code (`scadreport.py:218-223`) keeps only the 8 thickest layers of at least 0.4 mm, plus near-bottom and near-top slices.
- **Fix:** "...slices the part horizontally at up to ten representative heights (the thickest layers between distinct feature heights, plus near the bottom and top) and lists...".

**11. [ERROR] "Printable" is overstated (Table 3 "Printable 1st try", README:255; heatmap legend "no printable part", analyze.py:258; failure label "printable part with the wrong geometry").**
- `render.ok` only means OpenSCAD exported a non-empty STL. Watertightness, body count and orientation are not checked.
- Among first attempts that "rendered", the body count was wrong (floating or disconnected pieces) for: Gemma 4 E4B 6/9, Llama 3.2 5/8, Qwen2.5 1.5B 1/2, Qwen3.5 4B 1/1, Gemma 4 E2B 1/12.
- **Fix:** rename the column "Renders 1st try" and the legend entries "rendered but wrong (·)" / "nothing rendered (×)". Or define "printable" as rendered, watertight and with the expected body count, and compute it from `check.items`.

**12. [ERROR] Code extraction is described incorrectly (README:191), and early stop has a bug.**
- What the paper says: "the longest fenced OpenSCAD block".
- What `extract_code` (run_bench.py:52-65) actually does:
  1. take the longest block labelled `openscad`/`scad`, else the longest fenced block of any label;
  2. else, for an unterminated fence, everything after it;
  3. else, if any OpenSCAD keyword appears, the *whole reply*.
- For local models the stream also stops at the first complete block (`code_block_complete`), so the answer is effectively the *first* block.
- **Bug:** `code_block_complete` and `extract_code` strip only *closed* `<think>…</think>`. A snippet inside an unclosed think block stopped generation early three times (LFM2.5 micropestle a1/a2, pcr_tube_adapter a2: 1-8 line "files" taken from inside its reasoning).
- **Fix the code:** before matching, add `text = re.sub(r"<think>.*?(</think>|$)", "", text, flags=re.S)`.
- **Fix the text:** "The answer is the longest OpenSCAD-labelled fenced block (any fenced block if none is labelled; the text after an unclosed fence; or the whole reply if it contains OpenSCAD calls). Local replies stop once a complete block has arrived, so in practice the first block counts."

**13. [ERROR] The README is stale and some "AUTO" blocks are not automatic.**
- Abstract (README:16): "Results are being filled in".
- Table 3 (README:251-252): partial Haiku 9/12 and Qwen2.5-Coder 1.5B 0/9.
- Table 4: Haiku "Full hardware -".
- §6.5 (README:317): says the language ablation "runs after the main benchmark", but the Haiku language runs are done.
- Rule 12 (README:139) and tutorial line 238 are still placeholders.
- Table 3 has no "Same code after feedback" column, though `table_main` emits it, and the caption doesn't define it.
- `AUTO:abstract`, `results-overall`, `results-failures`, `results-frontier`, `results-language` and `conclusion` are **never written by analyze.py**. The only `replace_block` targets are table-models, table-prints, table-main, table-categories, table-failures and the four figures. But README:407 says analyze.py refreshes "the AUTO blocks in this README".
- **Fix:** rename the hand-written blocks `<!-- MANUAL:... -->`, or change README:407 to "tables and figures". Run `analyze.py` once both local models finish.

### Overclaims

**14. [OVERCLAIM] Tutorial line 151.** "A report like this … is what makes small free models usable. In our benchmark, models fixed many of their own mistakes this way."
- No local model passed any task after feedback. Five small models returned byte-identical code to 75-100% of repair messages (see §0).
- Only the hosted models repaired anything: Haiku 3 tasks, Sonnet 1.
- **Replace with:** "A report like this is the next best thing. In our benchmark it helped the hosted models fix most of their remaining mistakes. The small local models we tested usually ignored it and returned the same file, so with them, start a new chat or simplify the request instead."

**15. [OVERCLAIM] Tutorial Part 8 (lines 14, 229, 234-236).**
- Line 229: "You can run a capable model on your own laptop".
- Lines 234-236: the worked example is `qwen2.5-coder:7b`. That model scored 0/16; 15/16 of its first files failed to parse, and it returned identical code to all 32 repair requests.
- Line 14: "You do not need: … a paid AI subscription or a permanent internet connection". Read with Part 8, this implies the offline path works.
- **Replace line 229 with:** "You can run a model on your own laptop, with no account and no internet once it is downloaded. Be aware that none of the 14 small models we tested (up to 6.6 GB, thinking off) produced a correct part in our benchmark, so for now treat local models as an experiment and check everything."
- Change the example tag to a neutral placeholder (`ollama pull <model>`) until §6 names a recommendation.
- Line 14: "...a permanent internet connection (a free hosted chatbot works; see Part 8 for the offline option and its current limits)."

**16. [OVERCLAIM] Tutorial line 246.** "If it struggles in your language, try writing the numbers and geometry words … in English. See the paper's language results." The ablation covered one hosted model, found no significant effect, and never tested mixed-language prompts.
- **Replace with:** "We have not tested whether mixing in English geometry words helps; our language test (one hosted model) found no clear difference between English, Spanish, Hindi and Swahili requests."

**17. [OVERCLAIM] Language and model-ranking conclusions must stay null.**
- Draft for `results-language`: "With Claude Haiku 4.5, requests in Spanish, Hindi and Swahili passed 13, 12 and 11 of 16 tasks, against 14 in English. With one sample per task at the default temperature, none of these differences is statistically detectable (paired exact McNemar p ≥ 0.38). Which tasks failed differed between languages, which is what sampling noise would produce. We did not run the ablation on local models, which already passed nothing in English."
- Do not rank Haiku below Sonnet (p = 0.48).
- §1 question 3 should say it is answered only for one hosted model.

**18. [OVERCLAIM] "Small" is attached to evidence about large models.**
- README:29 says "small open models have performed poorly … (Badagabettu 2024; Alrashedy 2025; Dong 2026)", and README:231 is headed "Small models have done poorly".
- But the evidence quoted is **CodeLlama-70B** and "open-weight models of 8B parameters and up".
- **Fix:** "Open-weight models, even at 8-70B parameters, have performed poorly on CAD code generation without fine-tuning…", with the §5.5 heading "Open models have done poorly at CAD code without fine-tuning."
- Also verify against the reference notes:
  - README:344 cites Ahuja 2023 (MEGA) for "Code models degrade…". MEGA is not a code benchmark, so cite it only for the general multilingual gap.
  - README:25 cites Machado 2019 for "Among programmers of open labware, the most common choice is OpenSCAD". Check that the paper actually measured prevalence. If not, use "a widely used choice".

**19. [OVERCLAIM] "16 tested … designs" (README:9, 16, 40).** §9 says physical validation is "in progress".
- **Replace** "tested" with "geometry-checked", e.g. "16 parametric OpenSCAD lab designs, each rendered, sliced and checked against the benchmark's geometric tests (print validation in progress)".

**20. [OVERCLAIM] README:347.** "Models over about 7 GB will not fit alongside a desktop session in 16 GB of RAM; see §6.4". Nothing over 6.6 GB was tested, and §6.4 has no memory data.
- **Replace with:** "We tested models up to 6.6 GB; the 6.6 GB models ran in 16 GB of RAM with an 8,192-token context. We did not test larger ones."

**21. [OVERCLAIM] README:197.** "This is Claude as a student would actually use it". A student uses the chat app, not the CLI with a replaced system prompt and tools off.
- **Replace with:** "This is Claude with its vendor-default settings, not an equal-cost comparison."

**22. [OVERCLAIM] Validation claims (README:179-184; bench/build_refs.py) show internal consistency, not discrimination or fairness.**
- "0/240 cross-task false positives" is almost guaranteed by the bounding-box check, since no two tasks share a bbox.
- "fail when scaled by 3%" is caught mainly by bbox and volume.
- Invariance is tested for one of the seven non-identity symmetries (rot90 + mirror X).
- Nothing tests **false negatives**, i.e. correct alternative readings. #1 shows one exists.
- **Fix:** keep the list, but add: "These tests show the checks are self-consistent. They do not show that every correct reading passes; we found and fixed one false negative (funnel wall thickness, §5.2)." See #31 for the stronger tests.

### Methodology risks

**23. [RISK] The repair loop uses an oracle (README:192).**
- Feedback is sent only when the *hidden* checks fail, and the loop stops at the first pass. A real user can't know either.
- This makes "pass ≤3 tries" an upper bound. It can never turn a passing part into a failing one.
- **Replace** "This mimics a user who notices the part is wrong and pastes the report back" **with:** "Feedback is triggered by the hidden checks, so 'passed within three attempts' is an optimistic upper bound on what a user who must spot errors alone would get."

**24. [RISK] "Pre-specified" minimal-viable definition (README:233).**
- "Before running the benchmark we fixed what we would call a minimally viable…". The text first appears in commit `0c8dc60` (5 Oct 16:02). The Claude main run started at 15:35 and the local run at 15:47, and pilot runs are in `calib.log` at 15:33.
- No result could have favoured a local model by then (all local results are 0), but the claim can't be shown from the record.
- **Replace with:** "Before analysing any local-model results, we fixed…".
- Draft for the conclusion: "No tested model met the bar: all complete local models passed 0 of 16 tasks (95% upper bound 19%), and the two that need more than 10 minutes per task would have failed the time bar too."
- The models over the time bar so far: Granite median 14.8 min; Qwen3.5 4B 15.2 min, provisional; Qwen3.5 9B 27 min, provisional, from 2 tasks.

**25. [RISK] Confidence intervals and replication.**
- The Wilson CIs (README:255) treat tasks as samples from a population, and there is one sample per task. They capture neither run-to-run noise (important for Claude at T ≈ 1) nor the fixed task set.
- **Fix the caption:** "Wilson intervals over the 16 tasks of a single run; they do not include run-to-run variation."
- For partial models, the caption should say "over the tasks completed".

**26. [RISK] Bias: Claude drafted the tasks, checks, references and translations.** §9 discloses this. Sonnet's 16/16 also means the benchmark **cannot discriminate among hosted models** (ceiling effect).
- **Add to §9:** "The hosted models are at or near ceiling, so this task set cannot rank them."
- **Add** a canary string to `tasks.yaml` and the `designs/` headers so the public tasks can be detected in future training data.

**27. [RISK] The harness changed mid-study.**
- `bf70fa2` (20:37, matching "Terminated" in `main-local.log`) added `code_sha1`, the `InfraError` handling and the MAX_FACES guard, and changed `scadreport` output formatting (−0.00). Claude, Qwen2.5-Coder 7B and 3B, and the first 5 Qwen2.5-Coder 1.5B tasks ran on the earlier code; their feedback text differs cosmetically.
- `checks.py`, `tasks.yaml` and `system.md` are unchanged since `0c8dc60`, and `reference_stats.json` dates from 15:09 (before any run). Scoring is therefore very likely consistent, but this is not proven.
- **Suggest:** record `git rev-parse HEAD` in `meta`, and **rescore every saved `.scad` with the current checker** (a few minutes of renders) to confirm `passed`/`score` are unchanged. Report the result in one sentence.
- Context overflow was checked and is fine: the largest recorded prompt + reply was 7,591/8,192 tokens.

**28. [RISK] The repetition early stop can cut off legitimately repetitive code.**
- `repeating()` (run_bench.py:75) fires when the last 150 characters appear three times anywhere in the reply.
- It fired 23× (0.5B), 15× (Qwen2.5 1.5B), 13× (Qwen3.5 2B), and once each for Ministral and Llama.
- Spot checks look like genuine loops, but `ministral-3_3b/hose_barb_reducer_8_5_s0_a2` (2,992 characters of stacked barb code) is borderline.
- **Suggest:** require the repeats to be contiguous and periodic (`text.endswith(text[-k:] * reps)`), or k = 300. Report how many stops were "repetition".

**29. [RISK] Two checks are strict but defensible; say so.**
- Haiku's English enclosure failed only volume (+13%). It gave the lid lip a 1.5 mm floor, which works the same. Haiku's slide-rack slots came out 78 mm instead of 77.
- These are correct by the letter of the spec. A short "near-miss audit" (Haiku/Sonnet attempts scoring ≥ 0.9 that failed) would show readers that failures are real.
- Local near-misses:

  | Model | Task | Score | Only failed check |
  |---|---|---|---|
  | Gemma 4 E4B | micropestle | 0.91 | groove depth |
  | Qwen3.5 9B | tube rack | 0.89 | holes went through, no floor; reply hit the cap |

### analyze.py and figure bugs

**30. [SUGGEST] analyze.py.**
- (a) **No dedupe across runs.** `main_recs = runs["main"] + runs["main-claude"]` (line 437), and likewise `lang` + `lang-claude` (line 457). If a model ever appears in both, its tasks are counted twice and `complete` (`n >= 16`, line 145) becomes true wrongly. Dedupe on `(model, task, sample, lang, feedback)` after concatenating, keeping the latest `finished`, and set `complete = len({r["task"] for r in recs}) >= len(tasks)`.
- (b) `median_task_min` (line 149) takes the upper median. Use `statistics.median(walls)`.
- (c) `fig_frontier` plots partial models as if complete, e.g. Qwen3.5 9B at 27 min from 2 tasks. Skip rows with `not r["complete"]` or draw them hollow.
- (d) With every local model at 0%, the frontier and dumbbell figures are flat and carry no information. Plot instead (or as well) a graded outcome per model: % rendered, % with correct bbox and body count, mean best score.
- (e) `score` weights all check items equally, so a plain block with the right bbox scores 0.3-0.5. Label it "share of checks passed (not a quality measure)", or report the tiers from (d).
- (f) The meta for Claude runs should not record `temperature`/`num_predict` (see #7).

### Additional analyses to add (cheap, from existing data)

**31. [SUGGEST]** Each of these is a few lines over the JSONL; most numbers are already computed above.
1. **Failure taxonomy with "truncated"** (#3), plus a "geometry-as-value" column. Regex `^\s*\w+\s*=\s*(cube|cylinder|translate|union|difference|for|…)\s*[\(\[]` on first attempts gives:

   | Model | First files with geometry as a value |
   |---|---|
   | Qwen2.5-Coder 7B | 15/16 |
   | Qwen2.5-Coder 1.5B | 14/16 |
   | Qwen2.5-Coder 3B | 11/16 |
   | Ministral 3 | 8/16 |
   | Granite 4.2 | 8/16 |

   This is the single most useful finding for the tutorial's error table (tutorial:157-158).
2. **Graded outcome table** per model: renders on any attempt, valid single solid with the right bbox, mean best score, near-misses. For example, Gemma 4 E2B renders 12/16 with best score up to 0.70 and 6 tasks ≥ 0.5; Gemma 4 E4B renders 11/16 with 6 tasks ≥ 0.5; LFM2.5 and Qwen3.5 2B render 0/16.
3. **Truncation table:** share of attempts ending at the cap or as repetition, and median reply tokens per model (numbers in #2).
4. **Repair efficacy:** attempt-0 stage → final stage transitions, and the identical-code rate (already computed) in the text.
5. **Rescore sensitivity:** all saved `.scad` with the current checker, and again with the funnel fix (#1).
6. **Paired language table** (task × language, with the attempt that passed) and the McNemar p-values.
7. **Mutation tests for the checker:** per task, one variant per check (e.g. one hole shifted 1 mm, one feature missing, wrong count, depth +2 mm). Report the detection rate. Also run invariance under all 8 symmetries, and false-negative tests with alternative correct references (funnel perpendicular wall; `$fn` = 32; `center=true` vs translated).

### Minor

**32. [SUGGEST]**
- README:116-120: the "pitch came out wrong" excerpt's volume (158,139 mm³) is exactly the through-hole version (no 5 mm floor). Say "a rack whose pitch and hole depth came out wrong", or regenerate the excerpt. The slice line is cut short (the material area is omitted); add "…".
- `scadreport.py:267` reports circular *islands* by bounding length (`i['l']`) but holes by area-equivalent `d`. Use `i['d']` for consistency.
- The Ollama-reported parameter counts differ from Table §5.4 (Granite 4.2 3.7B vs "3B"; Ministral 3 3.8B vs "3.4B", probably including the vision encoder). Add a footnote "language-model parameters from model cards".
- Q4_K_M was confirmed for all local tags checked via `ollama show`.
- Tutorial:215: the ASA/PC "HDT about 85-110 °C" and the ASA emission claim (tutorial:223) are uncited. Azimi 2016 does not obviously cover ASA, so cite the Prusament TDS or drop "ASA".
- Verified correct:
  - Print totals: CSV sums 31.64 h, 482.9 g, US$12.07 at US$25/kg.
  - Wilson bounds as printed.
  - "0/240" = 16 × 15 pairs.
  - The seed-grid arithmetic (README:186).
  - The tutorial scadreport example (169,943 mm³, 211 g, 7,632 mm²).
  - Manifold is the default backend in OpenSCAD 2026.10.01.
  - The ANSI/SLAS A1 offsets.
  - All other task check geometry I recomputed: rod-clip bbox 27.37, seed bbox 84.7, hose-barb diameters, D-bore area 24.56 mm², NEMA z = 28 islands, gel-tank chambers 27 × 64.

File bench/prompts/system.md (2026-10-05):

You are an expert in OpenSCAD and in designing 3D-printable (FDM) parts for biology laboratories.
Write one complete, self-contained OpenSCAD file that builds exactly the part the user describes.

Rules:
1. Units are millimetres. Use the user's dimensions exactly - they were measured with calipers.
2. Put every dimension in a named variable at the top of the file, with a short comment.
3. Model the part in the print orientation the user gives: it rests on the XY plane at z = 0 and builds upward (+Z). Unless told otherwise, centre it on the origin in X and Y.
4. Use only built-in OpenSCAD: cube, cylinder, sphere, polygon, circle, square, linear_extrude, rotate_extrude, translate, rotate, mirror, union, difference, intersection, hull, for. Do not use include, use or any external library.
5. In difference(), make every cutting shape extend 0.01-1 mm past the faces it cuts, so no faces are exactly coplanar.
6. Set $fn = 64 (or more) on curved shapes so holes come out round and to size.
7. Build repeated features (hole grids, slots, teeth, grooves) with for loops.
8. The file must render to a valid solid with no errors.

Reply with only the code, in a single ```openscad code block.

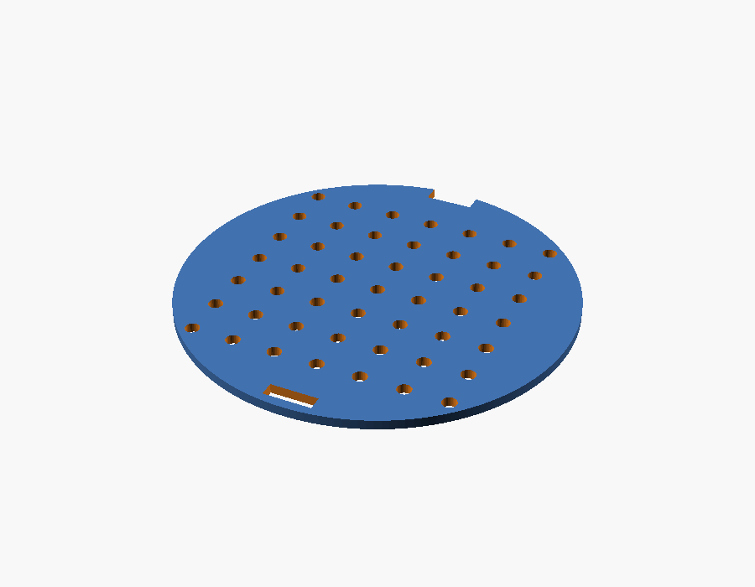
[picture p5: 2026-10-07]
figures/designs/seed_sowing_template.png

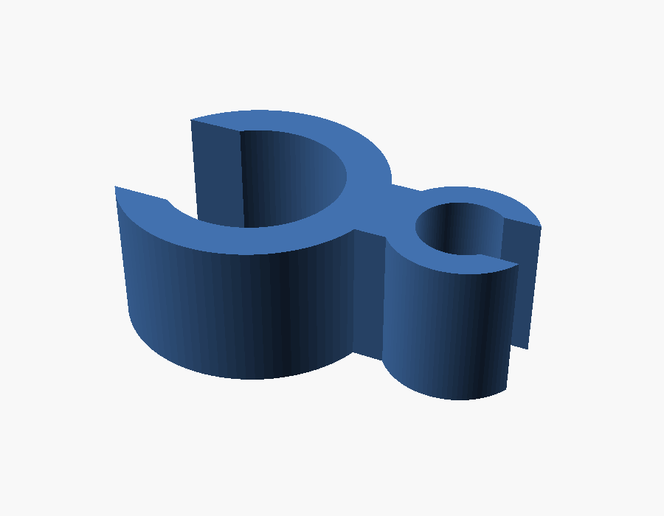
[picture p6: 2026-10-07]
figures/designs/rod_tubing_clip.png

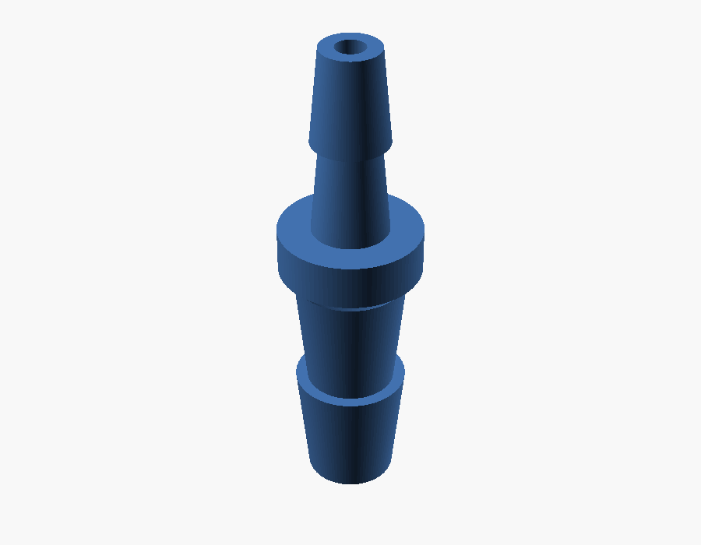
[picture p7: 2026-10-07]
figures/designs/hose_barb_reducer_8_5.png

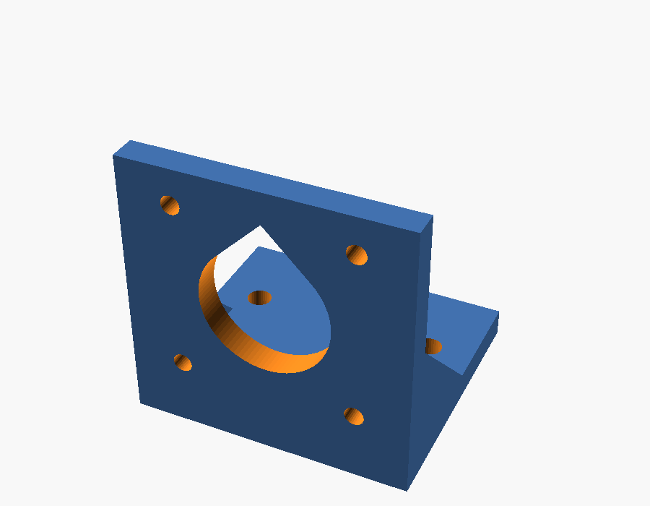
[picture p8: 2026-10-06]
figures/designs/nema17_motor_bracket.png

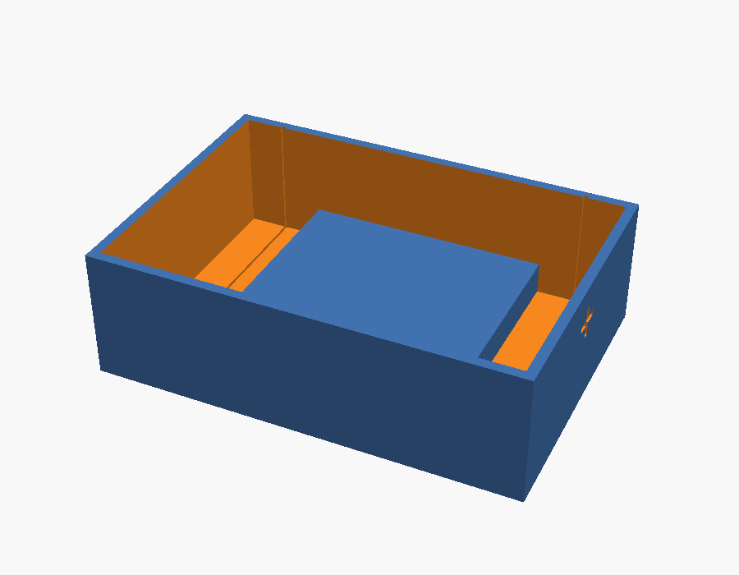
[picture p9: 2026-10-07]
figures/designs/mini_gel_tank.png

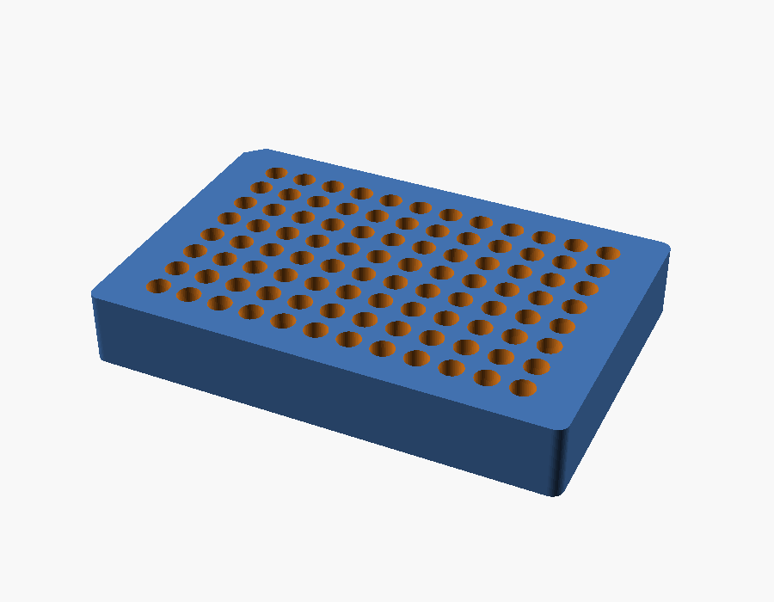
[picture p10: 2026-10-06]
figures/designs/pcr_tube_rack_sbs.png

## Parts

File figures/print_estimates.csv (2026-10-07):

task | category | title | print_time | hours | filament_cm3 | filament_g | cost_usd
tube_rack_1p5ml | benchware | 24-place 1.5 mL tube rack | 5h 26m 54s | 5.45 | 63.5 | 78.7 | 1.97
conical_rack_50ml | benchware | 50 mL conical tube rack, printed inverted | 4h 9m 34s | 4.16 | 55.6 | 69.0 | 1.73
slide_drying_rack | benchware | Microscope slide drying rack | 2h 46m 43s | 2.78 | 36.8 | 45.6 | 1.14
pcr_tube_rack_sbs | benchware | 96-place PCR tube rack, SBS footprint | 8h 8m 41s | 8.14 | 74.9 | 92.9 | 2.32
gel_comb_10well | tools | 10-well agarose gel comb | 11m 32s | 0.19 | 2.2 | 2.7 | 0.07
micropestle_1p5ml | tools | Micropestle for 1.5 mL tubes | 26m 34s | 0.44 | 1.5 | 1.9 | 0.05
lab_funnel_60mm | tools | 60 mm lab funnel | 37m 44s | 0.63 | 7.5 | 9.3 | 0.23
seed_sowing_template | tools | Seed-sowing template for a 90 mm Petri dish | 50m 24s | 0.84 | 9.5 | 11.8 | 0.3
dshaft_knob_6mm | quick-fixes | Replacement knob for a 6 mm D-shaft | 21m 7s | 0.35 | 4.0 | 5.0 | 0.12
pcr_tube_adapter | quick-fixes | 0.2 mL-in-1.5 mL tube adapter sleeve | 10m 41s | 0.18 | 1.2 | 1.5 | 0.04
hose_barb_reducer_8_5 | quick-fixes | Hose-barb reducer, 8 mm to 5 mm tubing | 18m 33s | 0.31 | 1.4 | 1.7 | 0.04
rod_tubing_clip | quick-fixes | Snap-on tubing clip for a lab stand rod | 6m 49s | 0.11 | 1.2 | 1.5 | 0.04
stirrer_fan_housing | hardware | Magnetic stirrer housing for an 80 mm PC fan | 3h 7m 49s | 3.13 | 43.5 | 53.9 | 1.35
nema17_motor_bracket | hardware | NEMA 17 motor L-bracket | 59m 51s | 1.0 | 11.4 | 14.2 | 0.35
enclosure_box_and_lid | hardware | Electronics enclosure with slip-fit lid | 1h 40m 19s | 1.67 | 27.3 | 33.9 | 0.85
mini_gel_tank | hardware | Mini gel-electrophoresis buffer tank | 4h 18m 57s | 4.32 | 68.1 | 84.4 | 2.11

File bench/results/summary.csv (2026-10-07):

model | label | family | hosted | size_gb | params_b | licence | n_tasks | pass1 | pass2 | pass3 | render1 | mean_best_score | median_task_min | total_min | gen_tok_s
claude:claude-haiku-4-5 | Claude Haiku 4.5 (hosted) | Claude | True |  |  | proprietary API | 16 | 11 | 13 | 14 | 15 | 0.988 | 1.943 | 35.63
claude:claude-sonnet-5-5 | Claude Sonnet 5.5 (hosted) | Claude | True |  |  | proprietary API | 16 | 16 | 16 | 16 | 16 | 1.0 | 0.1 | 1.923
qwen2.5-coder:0.5b | Qwen2.5-Coder 0.5B | Qwen2.5-Coder | False | 0.4 | 0.49 | Apache-2.0 | 16 | 0 | 0 | 0 | 0 | 0.0 | 0.791 | 17.267 | 37.706
qwen2.5:1.5b | Qwen2.5 1.5B (general) | Qwen2.5 | False | 0.99 | 1.54 | Apache-2.0 | 16 | 0 | 0 | 0 | 2 | 0.028 | 0.995 | 19.303 | 21.953
qwen2.5-coder:1.5b | Qwen2.5-Coder 1.5B | Qwen2.5-Coder | False | 0.99 | 1.54 | Apache-2.0 | 16 | 0 | 0 | 0 | 1 | 0.014 | 1.362 | 32.013 | 12.82
qwen2.5-coder:3b | Qwen2.5-Coder 3B | Qwen2.5-Coder | False | 1.9 | 3.09 | Qwen Research (non-commercial) | 16 | 0 | 0 | 0 | 3 | 0.087 | 1.867 | 31.098 | 10.703
qwen3.5:2b-q4_K_M | Qwen3.5 2B | Qwen3.5 | False | 1.9 | 2.27 | Apache-2.0 | 16 | 0 | 0 | 0 | 0 | 0.0 | 6.278 | 92.865 | 18.42
llama3.2:3b | Llama 3.2 3B | Llama 3.2 | False | 2.0 | 3.21 | Llama 3.2 Community | 16 | 0 | 0 | 0 | 8 | 0.148 | 2.238 | 43.598 | 10.294
granite4.2:3b | Granite 4.2 3B | Granite 4.2 | False | 2.2 | 3.0 | Apache-2.0 | 16 | 0 | 0 | 0 | 2 | 0.098 | 14.816 | 221.413 | 6.879
ministral-3:3b | Ministral 3 3B | Ministral 3 | False | 3.0 | 3.4 | Apache-2.0 | 16 | 0 | 0 | 0 | 1 | 0.057 | 3.554 | 67.755 | 8.957
qwen3.5:4b-q4_K_M | Qwen3.5 4B | Qwen3.5 | False | 3.3 | 4.66 | Apache-2.0 | 16 | 0 | 0 | 0 | 1 | 0.017 | 15.227 | 226.527 | 8.343
gemma4:e2b-it-q4_K_M | Gemma 4 E2B | Gemma 4 | False | 4.6 | 2.3 | Apache-2.0 | 16 | 0 | 0 | 0 | 12 | 0.359 | 3.575 | 56.127 | 18.62
qwen2.5-coder:7b | Qwen2.5-Coder 7B | Qwen2.5-Coder | False | 4.7 | 7.61 | Apache-2.0 | 16 | 0 | 0 | 0 | 1 | 0.007 | 3.093 | 57.662 | 5.847
lfm2.5:8b-a1b-q4_K_M | LFM2.5 8B-A1B (MoE) | LFM2.5 | False | 5.2 | 8.3 | LFM Open v1.0 (revenue cap) | 16 | 0 | 0 | 0 | 0 | 0.0 | 5.112 | 79.748 | 20.758
gemma4:e4b-it-q4_K_M | Gemma 4 E4B | Gemma 4 | False | 6.6 | 4.5 | Apache-2.0 | 16 | 0 | 0 | 0 | 9 | 0.274 | 6.128 | 96.743 | 11.709
qwen3.5:9b-q4_K_M | Qwen3.5 9B | Qwen3.5 | False | 6.6 | 9.65 | Apache-2.0 | 2 | 0 | 0 | 0 | 1 | 0.444 | 17.207 | 34.413 | 4.679

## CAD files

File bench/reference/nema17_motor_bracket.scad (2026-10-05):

// L-bracket for a NEMA 17 stepper motor (syringe pumps, peristaltic pumps, shakers)
// Category: full hardware. Base plate with two M4 holes, vertical motor plate with
// the 22 mm boss hole + 31 mm M3 pattern, two gussets. Motor body mounts on the
// back (-Y) side, shaft pointing over the base.
// Print: PETG, base on the bed, 0.2 mm layers, 5 perimeters, 30 % infill.
// SPDX-License-Identifier: CERN-OHL-P-2.0

/* [Bracket] */
base = [50, 45, 5];      // X, Y, Z: spans y = 0..45
plate = [50, 5, 50];     // vertical plate at y = 0..5
boss_d = 23;             // NEMA 17 centring boss is 22 mm
boss_z = 28;             // motor axis height
screw_d = 3.4;           // M3 clearance
screw_spacing = 31;      // NEMA 17 bolt pattern
mount_d = 4.5;           // M4 clearance
mount_pos = [[-17, 30], [17, 30]];
gusset_t = 5;
gusset_len = 20;

/* [Hidden] */
eps = 0.01;

difference() {
    union() {
        translate([-base.x / 2, 0, 0]) cube(base);
        translate([-plate.x / 2, 0, 0]) cube(plate);
        for (sx = [-1, 1])
            translate([sx * (base.x / 2 - gusset_t / 2) - gusset_t / 2, plate.y - eps, base.z - eps])
                rotate([90, 0, 90]) linear_extrude(gusset_t)
                    polygon([[0, 0], [gusset_len, 0], [0, gusset_len]]);
    }
    translate([0, -1, boss_z]) rotate([-90, 0, 0]) cylinder(d = boss_d, h = plate.y + 2, $fn = 96);
    for (sx = [-1, 1], sz = [-1, 1])
        translate([sx * screw_spacing / 2, -1, boss_z + sz * screw_spacing / 2])
            rotate([-90, 0, 0]) cylinder(d = screw_d, h = plate.y + 2, $fn = 32);
    for (p = mount_pos)
        translate([p.x, p.y, -1]) cylinder(d = mount_d, h = base.z + 2, $fn = 32);
}

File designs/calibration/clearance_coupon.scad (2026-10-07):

// Clearance coupon: find the fit tolerances of YOUR printer + material
// Category: calibration. Prints in about 35 minutes. A plate with six holes for a nominal
// 10 mm peg, each larger by 0.0-1.0 mm on the DIAMETER (engraved next to it; clearance
// per side = label / 2), plus a loose 10 mm test peg printed next to it.
// How to use: print with the settings you normally use. Push the peg's top end into each
// hole from the plate's top face (both first layers flare slightly):
//   - the smallest hole it enters with firm pressure = your PRESS fit
//   - the smallest hole it slides through freely      = your SLIDING fit
//   - the smallest hole it drops through by itself    = your LOOSE fit (tubes in racks)
// Write these down on your "printer facts" card and give them to the model in every
// design request (see tutorial/SETUP.md). Repeat for each material.
// Print: the material you want to test, 0.2 mm layers, 3 perimeters, no supports.
// SPDX-License-Identifier: CERN-OHL-P-2.0

/* [Coupon] */
// nominal peg diameter [mm]
peg_d = 10;
// added to the hole diameter [mm]
extra = [0, 0.2, 0.4, 0.6, 0.8, 1.0];
pitch = 16;
label_depth = 0.6; // 0.1
peg_h = 12;

/* [Hidden] */
$fn = 96;
eps = 0.01;
plate = [len(extra) * pitch + 4, 26, 4];  // X, Y, Z [mm]

// parameter checks: stop with a message instead of building a broken part
assert(peg_d + max(extra) <= pitch - 0.8, "holes overlap: increase pitch");
assert(peg_d + max(extra) <= 2 * (plate.y / 2 + 2) - 2 * 0.8, "holes are too big for the 26 mm plate");

difference() {
    translate([0, -plate.y / 2, 0]) cube(plate);
    for (i = [0 : len(extra) - 1]) {
        translate([2 + pitch / 2 + i * pitch, 2, -eps]) cylinder(d = peg_d + extra[i], h = plate.z + 2 * eps);
        translate([2 + pitch / 2 + i * pitch, -plate.y / 2 + 3.5, plate.z - label_depth])
            linear_extrude(label_depth + eps)
                text(str(extra[i]), size = 3.5, halign = "center", valign = "center");
    }
}
// the test peg, printed standing up next to the plate
translate([plate.x + 2 + peg_d / 2 + 4, 0, 0]) {
    cylinder(d1 = peg_d - 1, d2 = peg_d, h = 0.5);  // chamfer offsets the first-layer flare
    translate([0, 0, 0.5]) cylinder(d = peg_d, h = peg_h - 0.5);
}

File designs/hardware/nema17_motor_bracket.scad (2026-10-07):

// L-bracket for a NEMA 17 stepper motor (syringe pumps, peristaltic pumps, shakers)
// Category: full hardware. Base plate with two M4 holes, vertical motor plate with
// the 22 mm boss hole + 31 mm M3 pattern, two gussets. Motor body mounts on the
// back (-Y) side, shaft pointing over the base - screw the base down before mounting
// the motor, or the bracket tips backwards.
// The boss hole has a 45 deg teardrop top so its crown prints without sagging onto
// the motor's centring boss; check that the boss fits before final assembly.
// Print: PETG, base on the bed, 0.2 mm layers, 5 perimeters, 30 % infill.
// SPDX-License-Identifier: CERN-OHL-P-2.0

/* [Bracket] */
// X, Y, Z: spans y = 0..45
base = [50, 45, 5];
// vertical plate at y = 0..5
plate = [50, 5, 50];
// NEMA 17 centring boss is 22 mm
boss_d = 23;
// motor axis height
boss_z = 28;
// M3 clearance
screw_d = 3.4; // 0.1
// NEMA 17 bolt pattern
screw_spacing = 31;
// M4 clearance
mount_d = 4.5; // 0.1
mount_pos = [[-17, 30], [17, 30]];
gusset_t = 5;
gusset_len = 20;

/* [Hidden] */
eps = 0.01;

// parameter checks: stop with a message instead of building a broken part
assert(screw_spacing / 2 + screw_d / 2 <= plate.x / 2 - 0.8, "the motor screw holes do not fit the plate width");
assert(boss_z - screw_spacing / 2 - screw_d / 2 >= base.z, "the lower motor screws cut into the base: raise boss_z");
assert(boss_z + screw_spacing / 2 + screw_d / 2 <= plate.z - 0.8, "the upper motor screws run off the plate: lower boss_z or raise plate.z");

difference() {
    union() {
        translate([-base.x / 2, 0, 0]) cube(base);
        translate([-plate.x / 2, 0, 0]) cube(plate);
        for (sx = [-1, 1])
            translate([sx * (base.x / 2 - gusset_t / 2) - gusset_t / 2, plate.y - eps, base.z - eps])
                rotate([90, 0, 90]) linear_extrude(gusset_t)
                    polygon([[0, 0], [gusset_len, 0], [0, gusset_len]]);
    }
    // teardrop: circle + 45 deg roof, extruded through the plate along Y
    translate([0, plate.y + 1, boss_z]) rotate([90, 0, 0])
        linear_extrude(plate.y + 2)
            hull() {
                circle(d = boss_d, $fn = 96);
                translate([0, boss_d / 2 * sqrt(2) - 0.01]) square(0.02, center = true);
            }
    for (sx = [-1, 1], sz = [-1, 1])
        translate([sx * screw_spacing / 2, -1, boss_z + sz * screw_spacing / 2])
            rotate([-90, 0, 0]) cylinder(d = screw_d, h = plate.y + 2, $fn = 32);
    for (p = mount_pos)
        translate([p.x, p.y, -1]) cylinder(d = mount_d, h = base.z + 2, $fn = 32);
}

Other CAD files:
bench/results/lang-claude/code/claude_claude-haiku-4-5/nema17_motor_bracket_s0_sw_a0.scad
bench/mutants/dshaft_knob_6mm__7mm_bore.scad
bench/mutants/gel_comb_10well__9_teeth.scad
bench/mutants/gel_comb_10well__wrong_pitch.scad
bench/mutants/micropestle_1p5ml__1_groove.scad
bench/reference/conical_rack_50ml.scad
bench/reference/dshaft_knob_6mm.scad
bench/reference/enclosure_box_and_lid.scad
bench/reference/gel_comb_10well.scad
bench/reference/hose_barb_reducer_8_5.scad
bench/reference/lab_funnel_60mm.scad
bench/reference/micropestle_1p5ml.scad
bench/reference/mini_gel_tank.scad
bench/reference/pcr_tube_adapter.scad
bench/reference/pcr_tube_rack_sbs.scad
bench/reference/rod_tubing_clip.scad
bench/reference/seed_sowing_template.scad
bench/reference/slide_drying_rack.scad
bench/reference/stirrer_fan_housing.scad
bench/reference/tube_rack_1p5ml.scad
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

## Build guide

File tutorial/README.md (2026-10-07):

# From prompt to bench: design your own lab hardware with AI and OpenSCAD

*A hands-on tutorial for students and lab staff. No CAD experience needed. Part of the [Prompt to Bench](../README.md) project · CC BY 4.0*

You will learn to turn "I need something that holds these tubes" into a printed part that fits, using a language model as your CAD assistant. The model writes the 3D design as a short program in **OpenSCAD**. Your job is to measure, describe, check and decide.

**Time:** about 3 hours for parts 1-4; the rest whenever you need it.
**You need:**

- a computer (Windows, macOS or Linux; 8 GB RAM is enough for most of this, 16 GB for local AI models);
- digital calipers (about US$10-20);
- access to an FDM 3D printer (your own, a shared one or a makerspace).

**You do not need:** a GPU or a permanent internet connection. A hosted chatbot is the most reliable option; see [Part 8](#part-8-working-offline-with-a-free-local-model) for the offline option and its current limits.

---

**New here? Start with [SETUP.md](SETUP.md):** our exact setup (Claude Code + Prusa MK4), the same workflow with any printer, slicer or chatbot, a setup-assistant prompt, and a 35-minute calibration print for your printer.

## Contents

1. [Install the tools](#part-1-install-the-tools)
2. [Your first part: a tube rack in 20 minutes](#part-2-your-first-part-a-tube-rack-in-20-minutes)
3. [Check the part before you print it](#part-3-check-the-part-before-you-print-it)
4. [Make it fit: coupons and clearances](#part-4-make-it-fit-coupons-and-clearances)
5. [Make it yours: parameters and the Customizer](#part-5-make-it-yours-parameters-and-the-customizer)
6. [From parts to hardware](#part-6-from-parts-to-hardware)
7. [Materials, cleaning and safety](#part-7-materials-cleaning-and-safety)
8. [Working offline with a free local model](#part-8-working-offline-with-a-free-local-model)
9. [Share what you made](#part-9-share-what-you-made)
10. [Exercises](#exercises)
11. [Cheat sheets: prompts, OpenSCAD, error messages](#cheat-sheets)

---

## Part 1. Install the tools

| Tool | What it does | Get it |
|---|---|---|
| **OpenSCAD** | turns code into a 3D model | [openscad.org/downloads](https://openscad.org/downloads.html). Use a recent **development snapshot**: its new geometry engine (Manifold) renders orders of magnitude faster than the old 2021.01 release. |
| **A slicer** | turns the model into printer instructions (G-code) | PrusaSlicer, OrcaSlicer, Cura or your printer's own slicer |
| **An AI model** | writes the OpenSCAD code | either a chatbot you already use, or a free local model (Part 8) |
| *Optional:* **Python 3 + `scadreport`** | measures what you actually built, so you or the AI can compare it with what you wanted | this repository: `pip install -r requirements.txt`, then `python tools/scadreport.py yourpart.scad` |

When OpenSCAD starts, open **Window** and make sure the **Editor**, **Console** and **Customizer** panels are visible. You need three keys:

- **F5** - quick preview
- **F6** - full render (do this before exporting)
- **F7** - export STL

## Part 2. Your first part: a tube rack in 20 minutes

### Step 1 - Measure

Take a 1.5 mL microcentrifuge tube and measure the outside diameter just below the lid hinge with your calipers. You will get about **10.8 mm**. A tube should drop into its hole, and printed holes come out a little small, so we will use **11.6 mm**: about 0.4 mm of clearance on each side (see Part 4).

> **Rule 1: measure; don't trust memory - yours or the AI's.** Models will confidently invent "standard" sizes. Give them numbers.

### Step 2 - Give the model its instructions (the starter prompt)

Paste this once at the start of a new chat. In tools that support it, paste it as the "system prompt" or "custom instructions". It is the same prompt every model saw in our benchmark ([`bench/prompts/system.md`](../bench/prompts/system.md)).

````text
You are an expert in OpenSCAD and in designing 3D-printable (FDM) parts for biology laboratories.
Write one complete, self-contained OpenSCAD file that builds exactly the part the user describes.

Rules:
1. Units are millimetres. Use the user's dimensions exactly - they were measured with calipers.
2. Put every dimension in a named variable at the top of the file, with a short comment.
3. Model the part in the print orientation the user gives: it rests on the XY plane at z = 0 and builds upward (+Z). Unless told otherwise, centre it on the origin in X and Y.
4. Use only built-in OpenSCAD: cube, cylinder, sphere, polygon, circle, square, linear_extrude, rotate_extrude, translate, rotate, mirror, union, difference, intersection, hull, for. Do not use include, use or any external library.
5. In difference(), make every cutting shape extend 0.01-1 mm past the faces it cuts, so no faces are exactly coplanar.
6. Set $fn = 64 (or more) on curved shapes so holes come out round and to size.
7. Build repeated features (hole grids, slots, teeth, grooves) with for loops.
8. The file must render to a valid solid with no errors.

Reply with only the code, in a single ```openscad code block.
````

### Step 3 - Describe the part

Write the request the way you would explain it to a careful colleague who cannot see your bench. Give every number, say which face sits on the printer bed, and say what is open and what is closed:

```text
Design a bench rack for 1.5 mL microcentrifuge tubes. It is a solid rectangular
block 106 mm long (X), 72 mm wide (Y) and 30 mm tall (Z). It has 24 vertical
holes in 4 rows (along Y) of 6 holes (along X), 16 mm centre-to-centre in both
directions, with the hole grid centred on the block. Each hole is 11.6 mm in
diameter and 25 mm deep, open at the top and closed at the bottom, leaving a
5 mm solid floor.
```

> **Rule 2: say how it sits on the bed.** "The base lies on the bed at z = 0" prevents most upside-down and floating parts.

### Step 4 - Render it

Copy the code the model returns into a new OpenSCAD file, save it as `rack.scad` and press **F6**.

- **If it fails:** the Console shows red `ERROR` or yellow `WARNING` lines. Copy them back into the chat and say "Fix this. Reply with the complete corrected file."
- **If it renders:** a good answer looks like our reference design, [`designs/benchware/tube_rack_1p5ml.scad`](../designs/benchware/tube_rack_1p5ml.scad):

```openscad
/* [Rack] */
// holes along X
cols = 6;
// holes along Y
rows = 4;
// centre-to-centre spacing [mm]
pitch = 16;
// tube body 10.8 mm + clearance (see header)
hole_d = 11.6; // 0.1
// blind holes, leaves a 5 mm floor
hole_depth = 25;
// block height [mm]
height = 30;

/* [Hidden] */
$fn = 64;
eps = 0.01;            // cutters overshoot by eps so no faces are coplanar
block = [cols * pitch + 10, rows * pitch + 8, height];  // 106 x 72 x 30 by default

difference() {
    translate([-block.x / 2, -block.y / 2, 0]) cube(block);
    for (i = [0 : cols - 1], j = [0 : rows - 1])
        translate([(i - (cols - 1) / 2) * pitch, (j - (rows - 1) / 2) * pitch, block.z - hole_depth])
            cylinder(d = hole_d, h = hole_depth + eps);
}
```

Read it once. It is a block **minus** (`difference`) 24 cylinders placed by two nested loops (`for`). The comment above each number is what the Customizer shows (Part 5), and the block size is computed from the hole grid, so changing `cols` or `pitch` keeps the walls intact. Most lab parts are boxes and cylinders, added and subtracted.

## Part 3. Check the part before you print it

Your eyes come first. Rotate the model and ask yourself:

- Is it the right way up?
- Are the holes open where they should be open, and closed where they should be closed?
- Is anything floating loose?

Then **measure**. You can do it inside OpenSCAD, but the easiest way is `scadreport`, which prints the facts about what you built:

```text
$ python tools/scadreport.py rack.scad
OPENSCAD: rendered OK in 0.5 s, no warnings.
SOLID: 1 separate body, watertight (valid solid); volume 165,652 mm3 (~205 g of PLA if printed solid).
BOUNDING BOX: X -53.00 .. 53.00 (size 106.00) | Y -36.00 .. 36.00 (size 72.00) | Z 0.00 .. 30.00 (size 30.00) mm
BED: lowest point at z = 0.00; contact area with the bed 7,632 mm2.
OVERHANGS: none steeper than 45 deg - prints without supports.
HORIZONTAL SLICES (cut through the part at height z above its lowest point):
  z=2.50: 1 solid region [outline: rectangle 106.00 x 72.00 centred (0.00, 0.00)]; 0 holes; ...
  z=17.50: 1 solid region [...]; 24 holes: 24 x circle d=11.59 [6 x 4 grid (X x Y), pitch X 16.00 / Y 16.00, ...]
```

Compare every line with your request:

- Size 106 x 72 x 30? ✓
- Floor solid at z = 2.5? ✓
- 24 holes of 11.6 mm on a 16 mm grid? ✓ (11.59: a 64-sided polygon is a hair smaller than a circle)

> **Rule 3: when something is wrong, paste the report into the chat.** A language model cannot see your part; a report like this is the next best thing. In our benchmark it helped Claude Haiku fix 3 of its 5 first-try failures. Some small local models (the Qwen2.5 family) almost always returned the same file - with them, start a new chat, simplify the request, or fix the code yourself.

**Common problems and what they mean:**

| You see | Usually means | Tell the model |
|---|---|---|
| `WARNING: Ignoring unknown function 'cube'` and `Current top level object is empty` | it wrote code like `rack = cube(...)`, treating shapes as values. That is not how OpenSCAD works. | "OpenSCAD shapes are modules, not functions. Rewrite it with `difference() { cube(...); ... }` and no variables holding shapes." |
| `Parser error: syntax error ... line N` | a typo, or a different language (`let x = ...;`, `def`, `{` in the wrong place) | paste the line number and the line |
| The holes look polygonal or come out small | `$fn` is missing | "Add `$fn = 64;` at the top." |
| Flickering or paper-thin skins over holes | cutters end exactly on a face | "Make every cutter 0.01 mm longer on both sides." |
| The part is upside down, sideways or floating | the orientation was ambiguous | restate: "the base lies on the bed at z = 0" |
| Two bodies where you expected one | parts touch but don't overlap | "Overlap the parts by 0.01 mm so they join." |
| The model keeps returning the same broken file | small models can get stuck | start a new chat with a shorter request, or ask for one feature at a time |

## Part 4. Make it fit: coupons and clearances

Printers are not perfect. Holes print slightly small, posts slightly fat, and the first layer squishes. **Never print the full part first.** Print a **coupon**: a thin slice that contains the features that must fit. In OpenSCAD, keep only the bottom 3 mm of any part with `intersection()`:

```openscad
intersection() {
    import("rack.stl");            // or paste your design here
    translate([-500, -500, 0]) cube([1000, 1000, 3]);
}
```

Or ask the model: "Make a 3 mm tall test coupon with just the first row of holes." Print it in 10 minutes, try your real tube, adjust `hole_d`, and repeat.

**Starting clearances** (per side; calibrate for your own printer and material):

| Fit | Start with | Example |
|---|---|---|
| loose (drops in) | 0.3-0.5 mm | tube in a rack hole |
| sliding | 0.2-0.3 mm | a lid lip in a box |
| press / snap | 0-0.1 mm, test it | a knob on a shaft |

Prusa suggests an Original Prusa is accurate to about 0.2 mm and that moving parts start at about 0.3 mm ([Prusa Knowledge Base](https://help.prusa3d.com/article/modeling-with-3d-printing-in-mind_164135)).

> **Rule 4: print the coupon first, then the part.**

## Part 5. Make it yours: parameters and the Customizer

Good designs put every number at the top. In OpenSCAD, open **Window → Customizer**: the variables appear as sliders and boxes. To make a 3 x 8 rack for 2 mL tubes, change `rows`, `cols` and `hole_d` and press F6. You don't need the AI any more for that part.

From a terminal you can also do `openscad -D cols=8 -D rows=3 -o rack.stl rack.scad`.

> **Rule 5: once a design works, change its numbers - don't regenerate it.** Every working `.scad` file is a template for the next lab. Our [design library](../designs/) has 16 of them.

## Part 6. From parts to hardware

Devices such as stirrers, pumps, rotators and microscopes are many parts plus electronics. Don't ask a model for "a magnetic stirrer". Instead:

1. **Pick off-the-shelf parts first.** A PC fan, a stepper motor, magnets, screws. Their dimensions are your interfaces: write them down from the datasheet or your calipers. For example, an 80 mm fan has mounting holes 71.5 mm apart, and a NEMA 17 motor has a 31 mm bolt square and a 22 mm boss.
2. **Design one part at a time**, each with its interface numbers in the request. Our [stirrer housing](../designs/hardware/stirrer_fan_housing.scad) and [motor bracket](../designs/hardware/nema17_motor_bracket.scad) show how.
3. **Print it upside down if that removes supports.** The stirrer housing is modelled with its top plate on the bed.
4. **Assemble, test and write down what you changed.**

Keep electronics low-voltage. Use certified power supplies. Never improvise mains wiring.

## Part 7. Materials, cleaning and safety

| Material | Heat limit (approx.) | Good for | Avoid |
|---|---|---|---|
| **PLA** | softens at 55-60 °C | racks, templates, organisers, most benchware | autoclaves, hot water baths, heat blocks, agarose hotter than 60 °C, acetone, cars in summer |
| **PETG** | HDT about 68 °C | combs, funnels, clips, parts that flex or see ethanol | autoclaves (it deforms at 121 °C), long soaks in alcohols, phenol and chloroform (TRIzol), acetone |
| **ASA / PC blends** | HDT about 86-113 °C ([Prusament data sheets](https://prusament.com/)) | warm environments | autoclaves (printed PC deformed too in tests); they need an enclosed printer |

- **Cleaning.** Wiping with 70% ethanol, isopropanol or dilute bleach is fine; long soaks weaken parts. Ethanol *disinfects* but does not *sterilise* - it does not kill spores - and layer lines trap dirt and biofilm. For anything that touches media or cultures: soak at least 10 minutes in 70% ethanol, dry it in the flow hood and use it once, or keep it outside the dish (the seed template works from under the plate).
- **Never print:**
  - rotors or tube adapters for a commercial centrifuge (our tube adapter is for racks only - never spin it);
  - pressure vessels;
  - anything that holds mains voltage;
  - anything that touches patients.
- **Printing safely.** Ventilate the room (ABS emits far more ultrafine particles and fumes than PLA). Never leave a running printer unattended overnight unless your institution allows it.

The [paper's safety section](../README.md#8-safety-and-responsibility) has the references.

## Part 8. Working offline with a free local model

You can run a model on your own laptop, with no account and no internet once it is downloaded. Be aware that **none of the 14 small models we tested (up to 6.6 GB, on a laptop CPU) produced a correct part in our benchmark**, so for now treat local models as an experiment: check everything, and expect to fix the code yourself. We use [Ollama](https://ollama.com):

1. Install Ollama from [ollama.com/download](https://ollama.com/download). It is available for Windows, macOS and Linux.
2. Download a model **once**. If your connection is slow or metered, ask someone to copy it to you on a USB stick: on Linux the models live in `/usr/share/ollama/.ollama/models`, and in `~/.ollama/models` on macOS and Windows.
   ```bash
   ollama pull <model>          # e.g. gemma4:e4b-it-q4_K_M, the closest in our tests
   ```
3. Chat with it in a terminal (`ollama run <model>`), or connect any OpenAI-compatible chat app or OpenSCAD's experimental AI assistant to `http://localhost:11434`.

**Which model?** We tested 14 free models on a 2022 laptop without a GPU ([paper, §6](../README.md#6-results)). None passed a task. The code models (Qwen2.5-Coder) mostly wrote OpenSCAD as if it were another language; the reasoning models (Qwen3.5, Granite, LFM2.5) ran out of tokens; the Gemma 4 models (E2B, E4B) came closest, rendering most parts but rarely at the right size. If you have internet access, use a hosted chatbot. If you don't, a Gemma 4 model plus the starter prompt can draft code that you then fix by hand - which is also a fine way to learn OpenSCAD.

**Things to try with small models** (we have not measured whether they help):

- Use the starter prompt from Part 2, and one part per chat.
- Give every number. Small models cannot fill gaps sensibly.
- Ask for one feature at a time ("first the block with holes; then we add the chamfer").
- Always paste the error messages or the `scadreport` back. If the model returns the same broken file twice, start a fresh chat.
- Writing in your own language is fine for hosted models: our test (one hosted model) found no clear difference between English, Spanish, Hindi and Swahili requests. We have not tested whether mixing in English geometry words helps small models.

## Part 9. Share what you made

Share the **`.scad` file**, not just the STL. The `.scad` file is the editable "source" of your hardware. Include:

- a photo;
- your printer, material and slicer settings;
- what it is for;
- what you checked (calipers, fit test).

Say which AI model and prompt you used. A permissive open-hardware licence, such as CERN-OHL-P, lets other labs reuse your work. This repository welcomes new designs and benchmark tasks: see [CONTRIBUTING](../CONTRIBUTING.md).

## Exercises

1. **Warm-up.** Change the tube rack for 0.5 mL tubes. Measure them first! Print a one-row coupon and adjust the hole size until the tubes drop in without wobbling.
2. **Benchware.** Design a stand for the pipettes on your bench. Measure where the pipette rests and how far apart they need to be. Include the print orientation in your request.
3. **Quick fix.** Find a broken or missing knob, foot or clip in your lab. Measure the shaft or mounting, write a request, check it with `scadreport`, print a coupon of the critical fit, then print the part.
4. **Tool.** Design a seed-sowing or colony-picking template for the plates your lab uses. Make sure the corner holes stay inside the rim: use `scadreport` to check.
5. **Team project.** Build a magnetic stirrer from a PC fan, two magnets and a 12 V supply, starting from [`stirrer_fan_housing.scad`](../designs/hardware/stirrer_fan_housing.scad). Leave spacers so the magnets clear the top plate (the design has standoffs), glue the magnets with opposite poles facing up, and keep loose neodymium magnets away from children and pacemakers. Write a one-page safety note before switching it on.
6. **Compare models.** Give the same request to a hosted chatbot and to a local model. Count the rounds of feedback each needs. What does this tell you about which model to use for which part?

## Cheat sheets

### Prompt templates

- **New part:** "Design a [what] for [purpose]. Print orientation: [which face] lies on the bed at z = 0. Overall size [X x Y x Z] mm. Features: [each feature with its numbers and position]. [What is open / closed / through]."
- **Fix an error:** "OpenSCAD says: [paste the error lines]. Fix it and reply with the complete corrected file."
- **Fix the geometry:** "Here is a measurement report of the part your file produces: [paste the scadreport output]. Compare it with my specification, find what doesn't match and fix it."
- **Change a parameter:** do it yourself in the Customizer.
- **Explain:** "Explain what each line of this file does, as if to a biology student."

### OpenSCAD in 15 lines

```openscad
cube([x, y, z]);                       // box from the origin; cube(s, center=true) to centre it
cylinder(d = 10, h = 5, $fn = 64);     // d1 = / d2 = for a cone
sphere(d = 3, $fn = 48);
translate([x, y, z]) child();          // move
rotate([ax, ay, az]) child();          // rotate in degrees around X, Y, Z
mirror([1, 0, 0]) child();
union() { a(); b(); }                  // join (also the default)
difference() { a(); b(); c(); }        // a minus b minus c
intersection() { a(); b(); }           // keep the overlap
hull() { a(); b(); }                   // shrink-wrap around both
for (i = [0 : n - 1]) translate([i * pitch, 0, 0]) child();
linear_extrude(height = 2) polygon([[0,0], [10,0], [0,10]]);   // 2-D shape -> 3-D slab
rotate_extrude() polygon(profile);     // spin a 2-D (r, z) profile around Z: funnels, barbs
module my_part(size = 10) { cube(size); }  // define your own; call it with my_part(5);
/* [Section] */                        // Customizer tab; the comment line above a
// hole diameter [mm]                   //   parameter is its description, and a
hole_d = 11.6; // 0.1                  //   trailing number its step (// [1:10] = slider)
```

### Glossary

- **FDM:** printing by melting a plastic filament layer by layer.
- **Slicer:** software that turns a 3D model into G-code for the printer.
- **STL:** the triangle-mesh file you print.
- **`.scad`:** the editable source.
- **Perimeter:** an outline wall of extruded plastic, about 0.45 mm thick with a 0.4 mm nozzle.
- **Infill:** the internal lattice.
- **Overhang:** a surface printed over air. Up to about 45° is safe.
- **Bridge:** a flat span printed between two supports.
- **Clearance:** the gap you design between parts that must fit together.
- **Watertight / manifold:** a closed, valid solid, which is what a slicer needs.
- **Coupon:** a small test print of the critical feature.

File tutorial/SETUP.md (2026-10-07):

# Setting up: from our exact setup to whatever you have

*Part of the [Prompt to Bench](../README.md) tutorial · CC BY 4.0*

This page has three parts:

- [A](#a-our-exact-setup): how the author's setup works: Claude Code, an Original Prusa MK4, PrusaSlicer and OpenSCAD.
- [B](#b-any-printer-any-slicer-any-chatbot): the same workflow with whatever printer, slicer and AI you have, including free and offline options.
- [C](#c-calibrate-once-your-printer-facts-card): a 35-minute calibration print that makes every design fit better on *your* printer.

You do not need the setup in A. Most of the value is in B and C.

---

## A. Our exact setup

| Piece | What we use | Cost |
|---|---|---|
| AI assistant | [Claude Code](https://code.claude.com/docs/en/setup) in a terminal | needs a paid Claude plan (Pro, Max, Team, Enterprise) or an API account; not on the free plan; [supported countries](https://www.anthropic.com/supported-countries) only |
| CAD | [OpenSCAD](https://openscad.org/downloads.html) development snapshot (Manifold engine) | free |
| Slicer | [PrusaSlicer](https://github.com/prusa3d/PrusaSlicer/releases) (on Linux, the Flathub package `com.prusa3d.PrusaSlicer`) | free |
| Printer | Original Prusa MK4, 0.4 mm nozzle | about US$650-1,000 for the current MK4S |
| Checking | [`scadreport.py`](../tools/scadreport.py) from this repository (Python 3) | free |
| Computer | a 2022 Linux laptop, no GPU | |

### 1. Install the tools

```bash
# Claude Code (macOS, Linux, WSL). Windows PowerShell: irm https://claude.ai/install.ps1 | iex
curl -fsSL https://claude.ai/install.sh | bash
claude --version

# OpenSCAD: download a development snapshot for your system from
#   https://openscad.org/downloads.html  (section "Development Snapshots")
openscad --version

# PrusaSlicer on Linux via Flathub (or the installer for Windows/macOS)
flatpak install flathub com.prusa3d.PrusaSlicer

# this repository, for scadreport, the designs and the starter prompt
git clone https://github.com/ATinyGreenCell/prompt-to-bench.git
cd prompt-to-bench && python3 -m venv .venv && .venv/bin/pip install -r requirements.txt
```

Open PrusaSlicer once and run its configuration wizard for your printer. The wizard installs the printer profiles that the command line uses later.

### 2. Make a project folder that teaches Claude Code the workflow

Claude Code reads a file called `CLAUDE.md` in the folder you start it from and follows it. We provide one ([`claude-code/CLAUDE.md`](claude-code/CLAUDE.md)). It contains the design rules, the render-and-check loop, the PrusaSlicer command for an MK4, and safety rules for it to follow.

```bash
mkdir -p ~/lab-parts/parts ~/lab-parts/build && cd ~/lab-parts
cp ~/prompt-to-bench/tutorial/claude-code/CLAUDE.md .
cp ~/prompt-to-bench/tools/scadreport.py .
# edit the "Printer facts" block in CLAUDE.md with your printer and your coupon results (part C)
claude
```

### 3. Work

Inside Claude Code, describe the part:

> Design a rack for six 15 mL tubes (I measured 16.8 mm across). Two rows of three, 25 mm apart, plate on the bed, 60 mm tall walls. Print a test coupon of one hole first.

Claude Code writes `parts/<name>.scad`, renders it with OpenSCAD and checks it with `scadreport`. It fixes what does not match, shows you the numbers, and slices when you ask. It asks permission before running each new kind of command. Allow `openscad`, `python3 scadreport.py` and `prusa-slicer` once each, and read anything else before you approve it.

Open the `.scad` in OpenSCAD to look at the part yourself (F5 to preview, F6 to render), and send the G-code to the printer from PrusaSlicer or a USB stick.

This repository was itself built this way. Every prompt and reply is in [`meta/BUILD_LOG.md`](../meta/BUILD_LOG.md).

---

## B. Any printer, any slicer, any chatbot

The workflow does not depend on Claude Code or Prusa. It needs four things:

| You need | Free options |
|---|---|
| a 3D printer | your own, a shared lab printer, a university makerspace or FabLab |
| a slicer for that printer | PrusaSlicer, OrcaSlicer, Cura, Bambu Studio, or your printer maker's own |
| OpenSCAD | free on Windows, macOS and Linux ([openscad.org](https://openscad.org/downloads.html)) |
| an AI that writes code | any chatbot (free tiers included), or a local model through [Ollama](https://ollama.com) (see [tutorial Part 8](README.md#part-8-working-offline-with-a-free-local-model) for its current limits) |

With a chat window instead of Claude Code, *you* run the loop:

1. Copy the code into OpenSCAD and press F6.
2. Paste any errors back into the chat.
3. Check the part (by eye, or with `python scadreport.py part.scad`).
4. Export the STL (F7) and open it in your slicer.

### The setup assistant prompt

Paste this into any chatbot. It asks about your situation and writes you a personal setup plan:

````text
You are helping me set up a workflow for designing and 3D printing small parts for a
biology lab with OpenSCAD and an AI assistant. Ask me the following questions one at a
time, then write me a step-by-step setup plan:

1. My operating system and whether I can install software (admin rights?).
2. My printer (make, model, nozzle size) or the printer I have access to, and who runs it.
3. Which slicer I use, or whether I need one.
4. My internet access (always, sometimes, rarely; any data limits).
5. Which AI I can use (a hosted chatbot, a paid plan, or only offline models), and my
   computer's RAM and GPU if I want to run a model locally.
6. Which materials I can print (PLA, PETG, ...) and what the parts will be used for
   (heat, chemicals, sterile work).
7. My experience with 3D printing and with code (none is fine).

The plan must include:
- exact install steps for OpenSCAD and my slicer on my system, and how to load my printer's profile;
- how to run the loop: describe the part with measured numbers -> AI writes OpenSCAD -> I render
  in OpenSCAD (F6) -> paste errors back -> check the size -> export STL (F7) -> slice -> print a
  small test coupon of the critical feature first;
- a short calibration: print a clearance coupon (a plate with holes 0.0-1.0 mm larger than a
  10 mm peg) and record my press, sliding and loose fits;
- a "printer facts" card I can paste at the top of every future design request (printer, nozzle,
  build volume, material, my measured clearances, max overhang about 45 degrees, minimum wall
  2 x nozzle width);
- what NOT to print for a lab (centrifuge rotors and adapters, pressure vessels, mains-voltage
  enclosures, anything touching patients) and the material limits that matter for my uses.
Keep it practical and short. Use plain language. If I am offline most of the time, plan for
downloading everything once (or getting it on a USB stick).
````

### The starter prompt for every design

Use the starter prompt from [tutorial Part 2](README.md#step-2---give-the-model-its-instructions-the-starter-prompt) at the start of every design chat, followed by your printer facts card (part C) and the request.

---

## C. Calibrate once: your printer facts card

Every printer and material prints holes a little differently. Measure yours once:

1. Print [`designs/calibration/clearance_coupon.scad`](../designs/calibration/clearance_coupon.scad) (about 35 minutes) with your normal settings and material. It is a plate with six holes for a 10 mm peg, from +0.0 to +1.0 mm on the diameter, and the peg itself. Push the peg's top end in from the plate's top face.

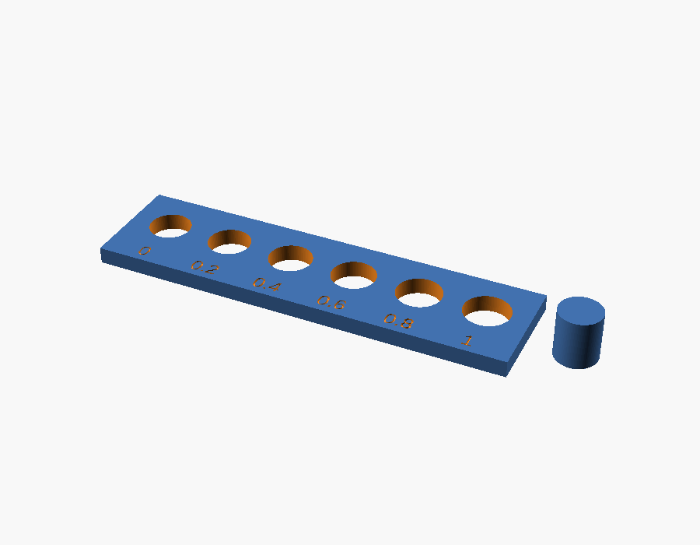
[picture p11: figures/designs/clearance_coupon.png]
Clearance coupon
   

2. Try the peg in each hole and note:
   - **press fit:** the smallest hole the peg enters with firm pressure;
   - **sliding fit:** the smallest hole it slides through freely;
   - **loose fit:** the smallest hole it drops through by itself.

   The clearance *per side* is half the number engraved by the hole.
3. Fill in this card and keep it. Paste it at the top of every design request, or into the "Printer facts" block of `CLAUDE.md`:

```text
PRINTER FACTS
Printer: <make/model>, <nozzle> mm nozzle, build volume <X x Y x Z> mm
Slicer: <name>, profile <name>
Material: <PLA/PETG/...>
Clearance per side (measured): press <a> mm, sliding <b> mm, loose <c> mm
Design rules: overhangs <= 45 deg without supports; walls >= <2 x nozzle> mm; flat face on the bed
```

Repeat the coupon for each material you use: PETG usually needs a little more clearance than PLA.

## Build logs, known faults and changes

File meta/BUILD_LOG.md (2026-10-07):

# Build log

How this repository was built: the human's prompts, Claude's replies and every tool call, exported from Claude Code sessions by [`meta/build_log.py`](build_log.py). Model reasoning, raw tool output and images are omitted; private details are redacted.

## Session 20fd6f84 (started 2026-10-05 18:38 UTC)

### 🧑 18:38 UTC

> I have been having so much fun using 3D printers + openSCAD + Claude and i want to write a tutorial on best practices for this workflow and ways in wich students can learn how to make for their labs, focusing on access globally and even testing out the minimal viable open weight model for this process. i currently have my Prusa Mk4, OpenSCAD installed, and have been doing stuff using it. Id like to leave out any confidential work related prints from the /home directory to protect client privacy but lets write a paper and a tutorial :)

### 🧑 18:38 UTC

> focus is Ai + 3D printing for biological laboratories. benchware, tools, quick fixes, full hardwares, etc.

I'll start by checking what's on this machine. I'll stay inside `~/printpaper` and won't open your other files in /home, so client work stays out of this.

<details><summary>15 tool call(s)</summary>

- `Bash` Inspect project folder and basic system specs — `ls -la && echo "---SYS---" && uname -a && nproc && lscpu | grep -E "Model name|Socket|Thread|Core" && free -h && df -h ~ /tmp 2>/dev …`
- `Bash` Check for GPUs available for local models — `(nvidia-smi --query-gpu=name,memory.total,memory.used,driver_version --format=csv 2>&1 || true); echo "---"; (lspci 2>/dev/null | grep -iE " …`
- `Bash` Check which CAD, slicer, LLM and doc tools are installed — `for t in openscad prusa-slicer PrusaSlicer prusaslicer ollama llama-cli llama-server python3 pip3 uv pandoc pdflatex xelatex lualatex latexm …`
- `Bash` Check OpenSCAD version and render backends — `openscad --version 2>&1; echo "---"; file -L $(command -v openscad) | cut -c1-200; echo "---"; openscad --info 2>&1 | grep -iE "version|mani …`
- `Bash` Check Ollama version, server and local models — `ollama --version 2>&1; echo "---"; ollama list 2>&1; echo "---"; curl -s -m 5 localhost:11434/api/version || echo "server not responding"; e …`
- `Bash` Check Python libs, git identity, API key names, network — `python3 --version; python3 -c "import numpy; print('numpy', numpy.__version__)" 2>&1 | tail -1; python3 -c "import trimesh; print('trimesh', …`
- `Bash` Check PrusaSlicer CLI and Claude Code version — `timeout 60 flatpak run --command=prusa-slicer com.prusa3d.PrusaSlicer --help 2>&1 | head -40; echo "---"; claude --version 2>&1`
- `Bash` Look for AI-related and backend options in OpenSCAD CLI — `openscad --help 2>&1 | grep -iE -B1 -A2 "ai|llm|assist|backend|summary" | head -40`
- `Bash` List newest and most popular models in the Ollama library — `curl -s -m 20 "https://ollama.com/library?sort=newest" | grep -oE 'href="/library/[a-zA-Z0-9._-]+"' | sed 's/href="\/library\///;s/"//' | he …`
- `Bash` Check PrusaSlicer sandbox access and bundled MK4 profiles — `flatpak info --show-permissions com.prusa3d.PrusaSlicer 2>&1 | grep -iE "filesystem|shared" ; echo "---"; flatpak run --command=ls com.prusa …`
- `Bash` Fetch gemma4 tag list to learn page structure — `cd [scratch] && curl -s -m 20 https://ollama.com/library/gemma4/ …`
- `Bash` Inspect HTML around one tag entry — `cd [scratch] && python3 - <<'EOF' …`
- `Bash` List small-model tags and sizes for newer Ollama families — `cd [scratch] && cat > ollama_tags.py <<'EOF' …`
- `Bash` List sizes for established small model families — `cd [scratch] && python3 ollama_tags.py qwen2.5-coder qwen3 gemma …`
- `Bash` Create project venv and install mesh-analysis deps — `python3 -m venv .venv && .venv/bin/pip install -q --upgrade pip && .venv/bin/pip install -q trimesh shapely networkx rtree scipy matplotlib  …`

</details>

Mesh-analysis libraries are installed. Next I'll time the models already on the laptop so I can size the benchmark realistically:

<details><summary>1 tool call(s)</summary>

- `Bash` Benchmark CPU inference speed of two local Qwen models — `cd [scratch] && for m in qwen2.5:1.5b qwen2.5:7b; do …`

</details>

### 🧑 18:48 UTC

> lets make a github for the paper so collaborators can contribute. the readme will be the paper, no?

<details><summary>3 tool call(s)</summary>

- `Bash` Write model-pull script and check GitHub CLI — `mkdir -p bench/logs && cat > bench/logs/pull_models.sh <<'EOF' …`
- `Bash` Download the open-weight model ladder in background — `bash bench/logs/pull_models.sh > bench/logs/pull_models.log 2>&1`
- `Agent` (sub-agent) Verify literature for paper

</details>

While that runs, I'm saving a few notes so future sessions remember this project and the privacy rule:

<details><summary>4 tool call(s)</summary>

- `Write` ~/.claude/projects/-home-seb-printpaper/memory/user-seb-maker-profile.md
- `Write` ~/.claude/projects/-home-seb-printpaper/memory/privacy-no-client-prints.md
- `Write` ~/.claude/projects/-home-seb-printpaper/memory/printpaper-project.md
- `Bash` Write memory index and check download progress — `cat > ~/.claude/projects/-home-seb-printpaper/memory/MEMORY.md <<'EOF' …`

</details>

### 🧑 18:54 UTC

> what should we call the project? Leveraging LLM's as a zero-skill entry into 3D printing for Research Labs?

<details><summary>6 tool call(s)</summary>

- `Bash` List relevant Claude Code CLI flags for headless runs — `claude --help 2>&1 | grep -iE -- "--(print|model|system-prompt|append-system|tools|allowed|disallowed|output-format|resume|session|max-turns …`
- `Bash` Show help for tools, bare and system-prompt flags — `claude --help 2>&1 | grep -nE -B2 -A6 -- "--tools |--bare|--system-prompt " | head -60`
- `Bash` Test a minimal headless Claude Haiku call — `cd [scratch] && timeout 120 claude -p --bare --model claude-haik …`
- `Bash` Test headless Claude call without bare mode — `cd [scratch] && timeout 180 claude -p --model claude-haiku-4-5 - …`
- `Bash` Test OpenSCAD STL export, JSON summary and PNG render — `cd [scratch] && cat > t.scad <<'EOF' …`
- `Bash` Probe trimesh section API on a test mesh — `.venv/bin/python - <<'EOF' …`

</details>

Next, the core tooling: a general-purpose geometry report (`tools/scadreport.py`). The benchmark feeds it back to models when a part fails, and students can use the same tool directly.

<details><summary>3 tool call(s)</summary>

- `Write` ~/printpaper/tools/scadreport.py
- `Bash` Confirm all models downloaded — `cat ~/printpaper/bench/logs/pull_models.log; ollama list | grep -vE "nomic|[redacted]|[redacted]"`
- `Bash` Write the 16 reference OpenSCAD designs and test-render each — `mkdir -p ~/printpaper/designs/{benchware,tools,quick-fixes,hardware} && cd ~/printpaper/designs &&  …`

</details>

All 16 render cleanly with no warnings. Here's the geometry report on two of them:

<details><summary>3 tool call(s)</summary>

- `Bash` Run the geometry report on three reference designs — `cd ~/printpaper && sed -i 's|// Category: full hardware. Base plate with M4 slots... holes, vertical motor plate with|// Category: f …`
- `Edit` ~/printpaper/tools/scadreport.py
- `Edit` ~/printpaper/tools/scadreport.py

</details>

Now the hidden checker. It is never shown to models. It compares each output against the spec, and it accepts any rotation or mirroring of the part on the bed, since those don't change how it prints:

<details><summary>1 tool call(s)</summary>

- `Write` ~/printpaper/bench/checks.py

</details>

Now the task file: 16 prompts written the way a student who has measured with calipers would write them, each paired with its hidden checks:

<details><summary>7 tool call(s)</summary>

- `Write` ~/printpaper/bench/tasks.yaml
- `Write` ~/printpaper/bench/build_refs.py
- `Bash` Render references and validate the hidden checker — `.venv/bin/python bench/build_refs.py 2>&1 | tail -40`
- `Bash` Fix seed template grid pitch and re-validate checker — `sed -i 's/^pitch = 10;$/pitch = 9;             \/\/ 10 mm would push the corner holes through the rim/' designs/tools/seed_sowing_template.s …`
- `Write` ~/printpaper/bench/prompts/system.md
- `Write` ~/printpaper/bench/run_bench.py
- `Bash` Smoke-test the harness on two models and two tasks — `.venv/bin/python - <<'EOF' …`

</details>

The test run is slower than I expected and is still going in the background, so I'm checking where it has got to:

<details><summary>3 tool call(s)</summary>

- `Bash` Check smoke-test progress and loaded models — `cat [scratch] echo ---; ls -la ~/printpaper …`
- `Bash` Inspect smoke-test replies and feedback — `cd ~/printpaper/bench/results/smoke && cat code/qwen2.5-coder_1.5b/tube_rack_1p5ml_s0_a0.reply.txt; echo; echo "=== a1 same as a0? = …`
- `Bash` Patch path handling and seeds, smoke-test with Claude Haiku — `pkill -f "run_bench.py --run smoke" ; sleep 1; cd ~/printpaper && .venv/bin/python - <<'EOF' …`

</details>

My process-kill command matched its own command line and killed itself. Re-running the patch without it:

<details><summary>4 tool call(s)</summary>

- `Bash` Check whether patches were applied — `cd ~/printpaper && pgrep -af run_bench | grep -v pgrep; grep -c "seed_base" bench/run_bench.py; grep -c "run next to the file" tools …`
- `Bash` Apply patches and smoke-test with Claude Haiku — `cd ~/printpaper && .venv/bin/python - <<'EOF' …`
- `Bash` Test checker and report feedback on a wrong design — `SP=[scratch] && sed 's/^pitch = 16; /pitch = 15; /; s/^hole_dept …`
- `Bash` Add edge slices to report; calibrate 4 models on one task — `.venv/bin/python - <<'EOF' …`

</details>

While those run, I'm reading the literature file the agent wrote:

<details><summary>16 tool call(s)</summary>

- `Bash` Show size and section outline of the references file — `F=[scratch] wc -l -c $F; grep -nE "^#{1,3} " $ …`
- `Read` [scratch]
- `Read` [scratch]
- `Read` [scratch]
- `Bash` Check calibration run progress — `cat ~/printpaper/bench/logs/calib.log`
- `Bash` Check calibration progress — `sleep 45; cat ~/printpaper/bench/logs/calib.log; ls -la ~/printpaper/bench/results/calib/code/*/ 2>/dev/null | grep -v "^tot …`
- `Bash` Check calibration progress — `cat ~/printpaper/bench/logs/calib.log; ls -la ~/printpaper/bench/results/calib/code/*/ 2>/dev/null | grep -v "^total\|^d" |  …`
- `Bash` Unload idle model and check calibration files — `curl -s localhost:11434/api/generate -d '{"model":"qwen3.5:2b-q4_K_M","keep_alive":0}' >/dev/null; ls -la ~/printpaper/bench/results …`
- `Bash` List top memory-consuming processes — `ps -eo rss,comm --sort=-rss | head -12 | awk '{printf "%7.0f MB  %s\n", $1/1024, $2}'; free -h | head -2`
- `Write` ~/printpaper/bench/prompts/translations.yaml
- `Bash` Check calibration progress and translation completeness — `cat ~/printpaper/bench/logs/calib.log; ls -la ~/printpaper/bench/results/calib/code/*/ 2>/dev/null | grep -v "^total\|^d" |  …`
- `Bash` Check whether calibration is still running — `date +%T; pgrep -af "run_bench" | grep -v pgrep | cut -c1-150; ollama ps; ls -la ~/printpaper/bench/results/calib/code/; head -c 120 …`
- `Bash` Run Claude reference models on all 16 tasks — `.venv/bin/python bench/run_bench.py --run main-claude --models claude:claude-haiku-4-5 claude:claude-sonnet-5-5 > bench/logs/main-claude.log …`
- `Bash` Check calibration results so far — `date +%T; cat ~/printpaper/bench/logs/calib.log; ls -la ~/printpaper/bench/results/calib/code/*/ | grep -E "reply" | awk '{p …`
- `Bash` Check output token counts of good solutions — `python3 -c " …`
- `Bash` Add token-cap and think options, stop calibration — `kill 977137 2>/dev/null; .venv/bin/python - <<'EOF' …`

</details>

Calibration is stopped (that exit code was my intentional kill). Next I'm launching the main local run from a script, so the exact command is saved in the repo:

<details><summary>1 tool call(s)</summary>

- `Bash` Write main-run script and record model digests — `cat > bench/run_main_local.sh <<'EOF' …`

</details>

That digest list picked up some of your other local models ([redacted] and others), which shouldn't go in a public repo. Filtering it down to the benchmark models only, then starting the run:

<details><summary>4 tool call(s)</summary>

- `Bash` Record digests for benchmark models only — `ollama list | awk 'NR>1{print $1, $2, $3$4}' | grep -E "^(qwen2\.5-coder:(0\.5b|1\.5b|3b|7b)|qwen2\.5:1\.5b|llama3\.2:3b|granite4\.2:3b|mini …`
- `Bash` Run main benchmark on 14 local open-weight models — `bash bench/run_main_local.sh > bench/logs/main-local.log 2>&1`
- `Bash` Test OpenSCAD preview and full-render PNG export — `mkdir -p figures/designs && openscad -o figures/designs/test_preview.png --imgsize 800,600 --viewall --autocenter --colorscheme Tomorrow des …`
- `Read` ~/printpaper/figures/designs/test_render.png

</details>

Headless renders work. Next is a script that renders all 16 designs and tiles them into one library figure for the paper:

<details><summary>5 tool call(s)</summary>

- `Write` ~/printpaper/tools/render_designs.py
- `Bash` Render all designs and build the library figure — `rm -f figures/designs/test_*.png && .venv/bin/python tools/render_designs.py 2>&1 | tail -3`
- `Read` ~/printpaper/figures/design_library.png
- `Bash` Use task titles/order and preview-mode renders — `.venv/bin/python - <<'EOF' …`
- `Read` ~/printpaper/figures/design_library.png

</details>

The figure is clean now. Two titles are still clipped, so I'm shortening them. They're labels only, so prompts and checks are unaffected:

<details><summary>11 tool call(s)</summary>

- `Bash` Shorten two titles and re-render the figure — `sed -i 's/^  title: 50 mL conical tube rack (printed upside down)$/  title: 50 mL conical tube rack, printed inverted/; s/^  title: Two-part …`
- `Bash` Set up isolated PrusaSlicer datadir and list MK4 profiles — `mkdir -p build/ps-datadir/vendor build/slice && flatpak run --command=cp com.prusa3d.PrusaSlicer /app/share/PrusaSlicer/profiles/PrusaResear …`
- `Bash` Declare MK4 as installed and list its profiles — `printf '[vendor:PrusaResearch]\nMK4 = 0.4\nMK4IS = 0.4\n' > build/ps-datadir/PrusaSlicer.ini && timeout 120 flatpak run --command=prusa-slic …`
- `Bash` Test-slice one reference part for the MK4 — `timeout 120 flatpak run --command=prusa-slicer com.prusa3d.PrusaSlicer --datadir ~/printpaper/build/ps-datadir --query-print-filamen …`
- `Bash` List Prusament PLA/PETG filament profile names — `grep -oE "^\[filament:Prusament (PLA|PETG)[^]]*\]" build/ps-datadir/vendor/PrusaResearch.ini | sort -u | head -30`
- `Bash` Find MK4-compatible PLA profile and slice test part — `grep -oE "^\[filament:Prusament (PLA|PETG)( @[^]]*)?\]" build/ps-datadir/vendor/PrusaResearch.ini | sort -u | grep -E "@PG|@MK4" ; for m in  …`
- `Write` ~/printpaper/tools/slice_library.py
- `Bash` Slice all 16 designs for the MK4 — `timeout 900 .venv/bin/python tools/slice_library.py 2>&1 | tail -20`
- `Bash` Show benchmark progress logs — `date +%T && echo "--- local ---" && cat bench/logs/main-local.log && echo "--- claude ---" && cat bench/logs/main-claude.log`
- `Bash` Inspect per-attempt timing for the 0.5B model — `python3 -c " …`
- `Bash` Stop the local run and clear its partial results — `for p in $(pgrep -f "bench/run_bench.py --run main --models qwen2.5-coder"); do kill $p; done; sleep 1; pgrep -af "run_bench.py --run main " …`

</details>

My kill pattern matched my own shell again. I'll use the bracket trick (`mai[n]`) so the pattern can't match itself:

<details><summary>1 tool call(s)</summary>

- `Bash` List running benchmark processes — `ps -eo pid,etime,args | grep -E "run_bench.py --run mai[n]" | cut -c1-120`

</details>

The local run is stopped and the Claude run is unaffected. Now the streaming patch: the harness stops on the first complete code block, cuts off verbatim loops, and caps replies at 1,024 tokens:

<details><summary>6 tool call(s)</summary>

- `Bash` Add streaming with early stop and loop detection — `curl -s localhost:11434/api/generate -d '{"model":"qwen2.5-coder:0.5b","keep_alive":0}' >/dev/null; rm -rf bench/results/main && .venv/bin/p …`
- `Bash` Test streaming harness on two quick tasks — `timeout 600 .venv/bin/python bench/run_bench.py --run smoke-stream --models qwen2.5-coder:1.5b --tasks tube_rack_1p5ml pcr_tube_adapter --ma …`
- `Bash` Update main-run script with new model order — `rm -rf bench/results/smoke-stream && cat > bench/run_main_local.sh <<'EOF' …`
- `Bash` Run main benchmark on local models (new protocol) — `bash bench/run_main_local.sh > bench/logs/main-local.log 2>&1`
- `Bash` Init git repo and fetch official license texts — `git init -q -b main && curl -sfL -m 30 https://creativecommons.org/licenses/by/4.0/legalcode.txt -o LICENSES/CC-BY-4.0.txt --create-dirs; cu …`
- `Bash` Fetch CERN-OHL-P-2.0 text from its canonical location — `curl -sfL -m 30 "https://gitlab.com/ohwr/project/cernohl/-/wikis/uploads/3eff4154d05e7a0459f3ddbf0674cae4/cern_ohl_p_v2.txt" -o LICENSES/CER …`

</details>

Status: both benchmarks are running in the background. I'm now writing the repo's support files (licences, contributor guide, citation info), and then the paper and tutorial.

<details><summary>1 tool call(s)</summary>

- `Bash` Write MIT license, LICENSE summary, gitignore, CITATION — `cat > LICENSES/MIT.txt <<'EOF' …`

</details>

Before writing the chart code for the results figures, I'm loading the data-visualisation guidance:

<details><summary>6 tool call(s)</summary>

- `Skill` skill=dataviz
- `Bash` Read the dataviz reference palette — `D=[scratch] wc -l $D/references/*.md; sed -n 1,200p $D/references/pa …`
- `Bash` Read form, marks and anti-pattern references — `D=[scratch] cat $D/references/choosing-a-form.md; echo ======; cat $ …`
- `Bash` Validate candidate chart palettes for light and dark modes — `D=[scratch] cd $D && node scripts/validate_palette.js "#86b6ef,#1c5c …`
- `Bash` Validate heatmap ramps and a 3-slot categorical set — `D=[scratch] cd $D && node scripts/validate_palette.js "#86b6ef,#3987 …`
- `Write` ~/printpaper/bench/models.yaml

</details>

Status: writing the analysis script that turns raw benchmark logs into the paper's tables and figures and keeps the README's results section up to date. Both benchmark runs are still going.

<details><summary>2 tool call(s)</summary>

- `Write` ~/printpaper/bench/analyze.py
- `Bash` Check progress and test the analysis script — `date +%T && cat bench/logs/main-local.log && echo --- && cat bench/logs/main-claude.log && .venv/bin/python bench/analyze.py --no-readme 2>& …`

</details>

The analysis pipeline works on partial data. So far Claude Haiku has passed 7 of its first 8 tasks; its one miss is the 96-place SBS rack. Let me look at the draft figures:

<details><summary>2 tool call(s)</summary>

- `Read` ~/printpaper/figures/fig_outcomes_light.png
- `Read` ~/printpaper/figures/fig_pass_rates_dark.png

</details>

The pass-rate chart reads well. The outcome heatmap's layout is broken: the title, category labels and axis labels collide or get clipped. Switching it to explicit margins:

<details><summary>2 tool call(s)</summary>

- `Bash` Fix heatmap margins and legend placement — `.venv/bin/python - <<'EOF' …`
- `Read` ~/printpaper/figures/fig_outcomes_light.png

</details>

Better, but the long task names still run into the legend. I'm adding short labels to `tasks.yaml` (for example "gel comb" or "motor bracket") and tightening the bottom margin:

<details><summary>2 tool call(s)</summary>

- `Bash` Add short task labels and re-render the heatmap — `.venv/bin/python - <<'EOF' …`
- `Read` ~/printpaper/figures/fig_outcomes_dark.png

</details>

The heatmap reads cleanly in both themes now. Checking on both runs before I start writing the paper:

<details><summary>7 tool call(s)</summary>

- `Bash` Check benchmark progress — `date +%T && tail -5 bench/logs/main-local.log && echo --- && tail -6 bench/logs/main-claude.log`
- `Write` ~/printpaper/README.md
- `Bash` Fetch exact titles of cited arXiv papers — `curl -s -m 20 "http://export.arxiv.org/api/query?id_list=2605.28579,2410.05340,2412.14042,2505.06507,2406.00144,2606.11152,2507.09792" | pyt …`
- `Bash` Fetch arXiv titles over HTTPS with redirects — `curl -sL -m 30 "https://export.arxiv.org/api/query?id_list=2605.28579,2410.05340,2412.14042,2505.06507,2406.00144,2606.11152,2507.09792&max_ …`
- `Bash` Apply reference fixes and cross-check citations — `.venv/bin/python - <<'EOF' …`
- `Bash` Add model/runtime citations and software references — `.venv/bin/python - <<'EOF' …`
- `Bash` Generate model and print-estimate tables into README — `.venv/bin/python - <<'EOF' …`

</details>

The tables weren't filled in, so something failed silently. Running it with the output visible:

<details><summary>2 tool call(s)</summary>

- `Bash` Run analysis and show errors — `.venv/bin/python bench/analyze.py 2>&1 | tail -8`
- `Bash` Verify README auto blocks are populated — `grep -n -A6 "AUTO:table-prints -->" README.md | head -9; grep -n -A4 "AUTO:table-models -->" README.md | head -5; grep -n -A6 "AUTO:fig-pass …`

</details>

The marker regex needs a blank line between an empty pair of markers, and mine have none. Fixing the pattern so empty blocks match too:

<details><summary>1 tool call(s)</summary>

- `Bash` Fix AUTO-block regex and regenerate README — `.venv/bin/python - <<'EOF' …`

</details>

The generated sections fill in correctly now and stay idempotent on re-runs. Next I'm recording the exact Python package versions for `requirements.txt`:

<details><summary>2 tool call(s)</summary>

- `Bash` List installed versions of required packages — `.venv/bin/pip freeze 2>/dev/null | grep -iE "^(trimesh|shapely|networkx|rtree|numpy|scipy|matplotlib|pyyaml|pillow)=="`
- `Bash` Write requirements.txt and Makefile — `cat > requirements.txt <<'EOF' …`

</details>

Now the contributor guide, the benchmark README and the design catalogue:

<details><summary>3 tool call(s)</summary>

- `Write` ~/printpaper/CONTRIBUTING.md
- `Write` ~/printpaper/bench/README.md
- `Write` ~/printpaper/designs/README.md

</details>

Checking progress before writing the tutorial:

<details><summary>4 tool call(s)</summary>

- `Bash` Check benchmark progress — `date +%T && cat bench/logs/main-local.log | tail -12 && echo --- && tail -8 bench/logs/main-claude.log`
- `Write` ~/printpaper/tutorial/README.md
- `Bash` Generate exact scadreport outputs for the docs — `SP=[scratch] && cp designs/benchware/tube_rack_1p5ml.scad $SP/ra …`
- `Bash` Correct the OpenSCAD speed claim in the tutorial — `.venv/bin/python - <<'EOF' …`

</details>

Time for a first commit, so the work is saved. It covers the infrastructure, designs, paper draft and tutorial; partial benchmark results will be committed once the runs finish:

<details><summary>3 tool call(s)</summary>

- `Bash` Make the first git commit of the project — `git add .gitignore LICENSE LICENSES CITATION.cff CONTRIBUTING.md README.md Makefile requirements.txt designs tools tutorial figures bench/RE …`
- `Bash` Fix resume key, add language-ablation script — `.venv/bin/python - <<'EOF' …`
- `Bash` Run language ablation for Claude Haiku (es, hi, sw) — `bash bench/run_lang.sh lang-claude claude:claude-haiku-4-5 > bench/logs/lang-claude.log 2>&1`

</details>

The Claude language run is going in the background. Next, a shareable web version of the tutorial for students. Checking what the publishing system recommends for this kind of page:

<details><summary>1 tool call(s)</summary>

- `Artifact` action=quickstart, intent=other, design_systems=False

</details>

No response requested.

### 🧑 00:26 UTC

> try again

The previous session ended and stopped all three background runs. Results are saved per task, so I'll check what finished and resume from there.

<details><summary>6 tool call(s)</summary>

- `Bash` Check which benchmark results survived — `date +%T; ps -eo pid,args | grep -E "run_bench.py --run mai[n]|run_ben[c]h" | cut -c1-100; for f in bench/results/*/results.jsonl; do echo " …`
- `Bash` Inspect local-model attempts for harness bugs — `python3 -c " …`
- `Bash` Look at qwen 7B output, errors and a Gemma reply — `cd ~/printpaper/bench/results/main/code && cat qwen2.5-coder_7b/tube_rack_1p5ml_s0_a0.scad; echo ====; python3 -c " …`
- `Bash` Check prompt growth across repair attempts — `cd ~/printpaper && python3 -c " …`
- `Bash` Count truncated replies per completed model — `python3 -c " …`
- `Bash` Drop truncated runs and raise token cap to 2048 — `python3 - <<'EOF' …`

</details>

Restarting the local benchmark where it left off. This time I'm detaching it with `setsid nohup`, so it keeps running even if this session ends again:

<details><summary>1 tool call(s)</summary>

- `Bash` Resume local benchmark detached from session — `setsid nohup bash bench/run_main_local.sh >> bench/logs/main-local.log 2>&1 < /dev/null & sleep 3; ps -eo pid,args | grep "run_bench.py --ru …`

</details>

The local run is going again (PID 10264), detached from this session. Committing the finished Claude results and the protocol fixes:

<details><summary>3 tool call(s)</summary>

- `Bash` Commit Claude results and preview summary table — `rm -rf bench/results/smoke && git add Makefile bench/run_bench.py bench/run_lang.sh bench/run_main_local.sh bench/README.md README.md bench/ …`
- `Bash` Check Sonnet timings for plausibility — `python3 -c " …`
- `Bash` Correct the hosted-reference thinking description — `python3 - <<'EOF' …`

</details>

The local run will take several more hours. The repo is otherwise ready, so I need your decision on GitHub:

<details><summary>1 tool call(s)</summary>

- `AskUserQuestion` How should I create the GitHub repo under your ATinyGreenCell account?

</details>

You chose public. Before anything goes out, I'm scanning the committed files for anything private: home-directory paths, your other local models, tokens or keys:

<details><summary>2 tool call(s)</summary>

- `Bash` Scan tracked files for private paths or secrets — `git add README.md && git commit -q -m "Describe hosted-reference thinking behaviour accurately …`
- `Bash` Sanitize paths, commit, create public repo and push — `sed -i 's|"~/printpaper/|"|g' bench/results/*/meta_*.json && python3 - <<'EOF' …`

</details>

The repo is live and public at **https://github.com/ATinyGreenCell/prompt-to-bench**. I'm saving its location and the run state to memory, then checking the local run:

<details><summary>1 tool call(s)</summary>

- `Bash` Update project memory and check local run — `python3 - <<'EOF' …`

</details>

The GitHub repo is live and public: **https://github.com/ATinyGreenCell/prompt-to-bench**. It has the paper (`README.md`), the student tutorial, the 16 lab designs, the benchmark code and the finished Claude results. The local open-weight benchmark is still running, so the paper's results, abstract and conclusion still say "pending".

**What happened to the earlier run:** the previous session ending stopped all three background jobs. Results are saved per task, so nothing finished was lost. Before resuming I found and fixed one fairness problem: my 1,024-token reply cap was cutting off verbose models before they finished their code. Gemma 4 E4B was truncated in 31 of 48 attempts. The cap is now 2,048, and the three affected models are being rerun. The run is now detached, so it survives this session ending too.

**Results so far:**

| Model | Passed (of 16 lab parts) |
|---|---|
| Claude Sonnet 5.5 | 16 (15 on the first try) |
| Claude Haiku 4.5 | 14 |
| Haiku with the request in Spanish / Hindi / Swahili | 13 / 12 / 11 |
| Qwen2.5-Coder 3B and 7B, local | 0 |

- **Small local models mostly don't produce valid OpenSCAD.** They write code in a style OpenSCAD can't parse, such as `rack = cube(...)`.
- **They ignore error feedback.** I checked whether this was my bug: the error messages do reach them, but at the low temperature I used, the 7B model returned a byte-identical broken file on all three attempts for every task. So far the answer to "what's the minimal viable open-weight model?" is that none tested yet clears the bar I fixed in advance.

**Still to come:**
- About 11 more local models at roughly 40–90 minutes each, so expect several hours on this laptop at full CPU. It resumes automatically if interrupted; stop it with `pkill -f run_main_local`.
- When it finishes: `.venv/bin/python bench/analyze.py` fills in the tables and figures. Then I'll write the results narrative, abstract, conclusion, the model advice in the tutorial and the shareable tutorial web page, and push.

**For you to fill in:**
- **Author details:** full name, affiliation and funding.
- **Competing interests:** declare co-authorship of any cited work. The literature search found a co-author "S. C. Cocioba" on McNair et al. 2024 (COBLE), which the paper cites; if that's you, it's a self-citation to disclose.
- **Licences:** I picked CC BY 4.0 for text, CERN-OHL-P-2.0 for designs and MIT for code. Change them if you prefer.
- **Translations:** the Spanish, Hindi and Swahili prompts were drafted with AI and still need native-speaker review.
- **Physical validation:** printing a few designs on your MK4 and measuring them is the biggest gap the paper names.

### 🧑 00:30 UTC

> the laptop shut down so idk how much of the download was done for the various models

I'll check which models are intact and how far the benchmark got before the shutdown.

<details><summary>1 tool call(s)</summary>

- `Bash` Check models, run state and results after shutdown — `date +%T; uptime -p; ollama list 2>&1 | awk 'NR>1{print $1, $3$4}' | grep -E "qwen|gemma4|granite|llama3.2|ministral|lfm" ; echo ---; ps -eo …`

</details>

The downloads were not affected: they all finished at 15:00, hours before the shutdown.

- **Models:** all 14 benchmark models are installed at their full sizes. Ollama only lists a model after the whole download has finished and its checksum is verified, so nothing here is half-downloaded.
- **Benchmark:** the laptop restarted at about 20:23, and the run I restarted at about 20:27 is still going (PID 10264). It's now on qwen2.5-coder 1.5B.
- **Results so far:** Qwen2.5-Coder 7B and 3B are complete (16 tasks each) and Coder 1.5B has 1 task. The results file has no corrupted lines.
- **Nothing lost:** the shutdown happened while the earlier run was in progress, and any task interrupted midway simply re-runs. The Claude results were already pushed to GitHub.

**If it shuts down again:** run `cd ~/printpaper && setsid nohup bash bench/run_main_local.sh >> bench/logs/main-local.log 2>&1 &` and it skips everything already finished. The run needs several hours at full CPU, so keep the laptop plugged in and set it not to suspend in the meantime.

### 🧑 00:30 UTC

> lets edge case, harden, find footguns, slowdowns, inefficiencies, etc across the entire project.

This is a full robustness audit, and one constraint shapes it: the benchmark is running right now. Anything that would change how a model is prompted or scored mid-run would make the results inconsistent. So I'll fix robustness bugs now, and list protocol-changing ideas separately for you to decide on. First, two quick checks: whether the shutdown has already left damage in the results, and whether any failures were really infrastructure errors.

<details><summary>3 tool call(s)</summary>

- `Bash` Audit result files for errors, corruption, duplicates — `python3 -c " …`
- `Read` ~/printpaper/bench/run_bench.py
- `Bash` Inspect benchmark-created Claude session folders — `ls ~/.claude/projects/ | grep p2b | head -3; d=$(ls ~/.claude/projects/ | grep p2b | head -1); ls ~/.claude/projects/$d | head; ls ~/.claude …`

</details>

Each of the 83 folders holds exactly one session file and was created by the benchmark (the path pattern is `/tmp/p2b_claude_*`), so I'll remove them. Now the remainder of the harness:

<details><summary>7 tool call(s)</summary>

- `Read` ~/printpaper/bench/run_bench.py
- `Bash` Harden run_bench.py against infra errors and data loss — `python3 - <<'EOF' …`
- `Bash` Harden scadreport and test edge cases — `sed -i '/^import glob$/d' bench/run_bench.py && python3 - <<'EOF' …`
- `Write` ~/printpaper/bench/test_harness.py
- `Bash` Run the new robustness test suite — `timeout 600 .venv/bin/python bench/test_harness.py 2>&1 | tail -30`
- `Bash` Fix test script and rerun the suite — `python3 - <<'EOF' …`
- `Bash` Flag library use; rerun tests — `python3 - <<'EOF' …`

</details>

All 22 tests pass. Status: the harness is hardened. Next come the analysis script, the slicing and render tools, and stopping the laptop from sleeping during runs.

<details><summary>8 tool call(s)</summary>

- `Bash` Locate analyze.py parts to fix — `grep -n "def load_runs" -A10 bench/analyze.py; grep -n "same = \|code_hash\|if False" bench/analyze.py`
- `Bash` Fix analysis loader, dedupe and repeat metric — `python3 - <<'EOF' …`
- `Bash` Atomically update run scripts to inhibit sleep — `for f in run_main_local run_lang; do python3 - "$f" <<'EOF' …`
- `Bash` Inhibit sleep for current run; remove junk sessions — `PID=$(pgrep -f "run_bench.py --run mai[n]"); echo pid=$PID; setsid nohup systemd-inhibit --what=sleep:idle:handle-lid-switch --who=prompt-to …`
- `Bash` Harden slicing and rendering helper scripts — `python3 - <<'EOF' …`
- `Bash` Check Ollama thread count and core types — `journalctl -u ollama --since "30 min ago" --no-pager 2>/dev/null | grep -iE "threads|n_threads|system_info" | tail -3; lscpu -e=CPU,CORE,MAX …`
- `Bash` Add test target and docs, commit and push — `python3 - <<'EOF' …`
- `Bash` Restart benchmark under the hardened harness — `kill $(pgrep -f "run_bench.py --run mai[n]") ; sleep 3; pgrep -f "run_bench.py --run mai[n]" || echo stopped; setsid nohup bash bench/run_ma …`

</details>

I went through the whole project, fixed what was broken, wrote 22 tests that exercise those fixes, and pushed everything (`bf70fa2`). The benchmark is running again on the hardened code, and the laptop can no longer suspend mid-run. None of the fixes changes how models are prompted or scored, so they don't affect consistency with results already collected.

**Data loss and wrong-results bugs (fixed):**
- **Language-run code was overwritten.** The Spanish, Hindi and Swahili runs saved code under the same filenames, so only Swahili's survived. The scores are intact; future runs keep separate files per language.
- **Runtime failures counted as model failures.** An Ollama crash, dropped connection or Claude rate limit was recorded as the model failing, and the resume logic then skipped that task forever. Now these are retried, never scored, and three in a row stop the run.
- **A power cut could corrupt the results file.** Writes are now flushed to disk immediately, and a half-written line is dropped on restart so that task reruns.
- **Two copies of the run could write the same file.** My own "if it shuts down, run this" instructions could have caused that. A lock now refuses a second copy.
- **A missing translation silently fell back to English** and would have been counted as Hindi or Swahili. It's now an error.
- **The "same code after feedback" metric was always 0.** It read a field that was never written; it's now computed properly.

**Footguns (fixed):**
- The Claude runs left 83 junk sessions in your Claude Code history. They're deleted, and each conversation now cleans up after itself.
- If a model uses an external library such as BOSL2, the result depends on what's installed on the machine running the benchmark. Those attempts are now flagged.
- Editing a bash script while bash is running it can execute garbage, so the run scripts are now replaced atomically.
- `scadreport` printed `-0.00`, leaked a temp folder per run, had no guard against runaway meshes and gave a raw traceback when OpenSCAD was missing. All fixed.
- The slicing script only worked with the Flathub PrusaSlicer, and the renderer assumed a display. Both now fall back or fail with a clear message.

The new test suite (`make test`) covers bad model output (empty files, 2-D-only, syntax errors, functional-style code, missing includes, stray bodies, oversized meshes), checker edge cases (shifted, too-small holes, no floor, polygonal holes, upside down), runtime errors, damaged-file resume, the lock, and the translation guard. All 22 pass.

**My own mistake during cleanup:** the safety check in my session-folder deletion didn't actually run, because the folder names start with `-` and `ls` read them as options. The deletion was still correct, since I had already checked all 83 folders by hand, but it was luck rather than the check.

**Slowdown finding:** Qwen2.5-Coder 7B returned **identical code in 32 of 32 repairs**, and the 3B in 31 of 32. For these models, two thirds of the compute goes into regenerating the same broken file.

**Decisions for you.** Each of these changes the protocol, so I haven't applied any:

1. **Stop a conversation when the model repeats identical code.** This would cut roughly 30–60% of the remaining runtime (several hours) with almost no effect on scores.
2. **Use a higher temperature (e.g. 0.7) on repair attempts only.** This gives feedback a chance to actually change the answer, which is arguably a fairer test of the feedback loop. It would mean rerunning the two models already finished, about 1.5 h.
3. **Tell the model when its reply was cut off** at the token cap. At the moment it only sees "syntax error".
4. **Recover the lost Spanish and Hindi code** by rerunning those 32 Claude conversations. Only needed if you want the code itself, not just the scores.
5. **Test a higher thread count for prompt processing.** Ollama uses the 4 performance cores for everything, which is right for generation, but prompt processing might be faster with more. This needs a 10-minute test while the benchmark is paused.

One cosmetic inconsistency remains: the two models that already finished saw `-0.00` in their measurement feedback, while the rest see `0.00`. The geometry information is identical.

### 🧑 14:18 UTC

> whats running in the background? my laptop was running hot all night. nothing should be running rn

That's the benchmark I restarted last night. It's detached from this session, so it kept running. Checking what's active, then stopping it:

<details><summary>3 tool call(s)</summary>

- `Bash` List benchmark-related processes and loaded models — `date +%T; ps -eo pid,etime,pcpu,args --sort=-pcpu | grep -E "run_ben[c]h|run_main_loca[l]|systemd-inhibi[t]|tail --pi[d]|llama-serve[r]|olla …`
- `Bash` Stop benchmark, inhibitor and unload model — `kill 33826 33832 33828 2>/dev/null; sleep 2; curl -s localhost:11434/api/generate -d '{"model":"qwen3.5:4b-q4_K_M","keep_alive":0}' >/dev/nu …`
- `Bash` Summarise how much of the benchmark finished — `python3 -c " …`

</details>

It got through 12 of the 14 models, plus 7 of 16 tasks on Qwen3.5 4B. Every local model passed **0 of 16** lab parts. Gemma 4 E4B also scored 0 with the larger token cap, so the earlier truncation wasn't hiding a pass. Only Qwen3.5 4B (9 tasks left) and Qwen3.5 9B are untested. Given the pattern, they're unlikely to change the conclusion: none of the open-weight models tested reaches the "minimally viable" bar I fixed in advance on a CPU-only laptop, while hosted Claude passes 14–16 of 16. Everything finished is saved, so nothing is lost.

From now on I won't start anything long-running without telling you how long it will take and getting your OK. The remaining two models would take about 3–4 more hours.

Some options:
1. **Stop here.** Write up the results with those two models marked "not run", then finish the paper's results, abstract, conclusion and tutorial advice. That only takes a few minutes of CPU for the figures.
2. **Finish only Qwen3.5 4B** (about 1 hour), at a time you choose, with the laptop plugged in.
3. **Run the remaining models later**, e.g. tonight, with my "stop when the model repeats identical code" change, which would roughly halve the time.

### 🧑 14:20 UTC

> finish the remaining models but be sure we are not wasting watts and time with a possible mistake

Before spending more power, I'll check two things: that the 0/16 results aren't a pipeline mistake, and that the remaining two models won't just burn hours on the same failure.

<details><summary>5 tool call(s)</summary>

- `Bash` Check render rates, truncation, near-miss scores — `python3 -c " …`
- `Bash` Inspect Gemma micropestle near-miss — `python3 -c " …`
- `Bash` Inspect a truncated Qwen3.5 4B reply — `cd ~/printpaper/bench/results/main/code/qwen3.5_4b-q4_K_M && ls | head -3; f=$(ls *_a0.reply.txt | head -1); echo "== $f"; head -c 7 …`
- `AskUserQuestion` How should I finish the two Qwen3.5 models (4B: 9 tasks left, 9B: all 16)?
- `Bash` Pilot Qwen3.5 9B on two easy tasks — `cd ~/printpaper && .venv/bin/python bench/run_bench.py --run main --models qwen3.5:9b-q4_K_M --tasks tube_rack_1p5ml pcr_tube_adapte …`

</details>

The pilot is running. I'll check the results when it finishes, in roughly 15–25 minutes, and won't start anything else meanwhile, so it gets clean CPU.

<details><summary>2 tool call(s)</summary>

- `Bash` Inspect pilot results for Qwen3.5 9B — `cd ~/printpaper && cat [scratch] python3 -c …`
- `AskUserQuestion` The 9B pilot is promising (feedback improves it), but the full run is about 5 h of CPU in total. What should I do?

</details>

### 🧑 21:26 UTC

> set up a zenodo for the github immediately

<details><summary>2 tool call(s)</summary>

- `Bash` Finish Qwen3.5 4B remaining tasks (attended) — `systemd-inhibit --what=sleep:idle:handle-lid-switch --who=prompt-to-bench --why="benchmark: qwen3.5 4b" .venv/bin/python bench/run_bench.py  …`
- `Bash` Add Zenodo metadata, commit and push — `cat > .zenodo.json <<'EOF' …`

</details>

The metadata is pushed (`1c455e0`), and the repo has no releases yet, so nothing has been missed.

**Your part takes about 2 minutes:**
1. Go to **https://zenodo.org** and click **Log in → Log in with GitHub**, signed in as ATinyGreenCell. Approve the Zenodo authorisation.
2. Open **https://zenodo.org/account/settings/github/**. Click **Sync now** if the repo isn't listed, then flip the switch next to **ATinyGreenCell/prompt-to-bench** to **On**.
3. Tell me when it's on.

**Then I'll** create the first GitHub release (`v0.1.0`, marked as a preprint snapshot with the local results still being completed). Zenodo archives it within a minute or two and mints:
- a **version DOI** for v0.1.0;
- a **concept DOI** that always resolves to the newest version. That's the one to cite. Later releases, such as the one with full results, get new version DOIs under the same concept DOI.

I'll then add the DOI badge to the README and `CITATION.cff`.

**One thing before the release:** the archive's author field is currently just "Seb". DOI records are usually cited as "Surname, Given name", optionally with an ORCID and an affiliation. Send me those and I'll put them in first, or I can release now and you fix it on Zenodo afterwards, since metadata stays editable there.

Meanwhile, Qwen3.5 4B is running its remaining 9 tasks in the background, with sleep blocked only for that job.

### 🧑 21:28 UTC

> i dont see it in the list?[Image #1]
> [screenshot omitted]

The list is stale: the panel says **"updated 2 months ago"**, and the repo was created yesterday. To refresh it:

1. Click **Sync now**, at the top right of the "GitHub Repositories" box.
2. Wait about 10–30 seconds, then reload the page.
3. Scroll down the **Repositories** list. It's alphabetical, so **ATinyGreenCell/prompt-to-bench** should appear after `bioconda-recipes`. Flip it to **On**.

If it still doesn't appear after syncing, the usual cause is the Zenodo app's permissions on GitHub. Check **github.com/settings/applications** → **Authorized OAuth Apps** → **Zenodo**. Personal public repos normally show up without any extra steps.

Tell me once it's switched on, and I'll create the `v0.1.0` release to trigger the DOI.

### 🧑 21:29 UTC

> switch is on! please put Sebastian S. Cocioba and for affil put Binomica Labs. Use my ORCID if need be.

Updating the author everywhere to Sebastian S. Cocioba, Binomica Labs. You didn't give me your ORCID iD, and I won't guess an identifier that goes into DOI metadata, so I'm looking it up in the public ORCID registry first:

<details><summary>3 tool call(s)</summary>

- `Bash` Search public ORCID registry for Cocioba — `curl -s -m 20 -H "Accept: application/json" "https://pub.orcid.org/v3.0/expanded-search/?q=family-name:Cocioba&rows=10" | python3 -c " …`
- `Bash` Update author metadata, commit and push — `python3 - <<'EOF' …`
- `Bash` Create v0.1.0 GitHub release to trigger Zenodo — `gh release create v0.1.0 -R ATinyGreenCell/prompt-to-bench --target main --title "v0.1.0 - preprint snapshot" --notes "First archived snapsh …`

</details>

The release is live. Zenodo usually picks it up within a minute or two. I'll wait for the DOI with a background check that gives up after 8 minutes:

<details><summary>1 tool call(s)</summary>

- `Bash` Wait for Zenodo to mint the DOI — `for i in $(seq 1 32); do r=$(curl -s -m 15 "https://zenodo.org/api/records?q=%22Prompt%20to%20Bench%22%20AND%20creators.name:Cocioba&sort=mo …`

</details>

The author metadata is in and release **v0.1.0** is published (https://github.com/ATinyGreenCell/prompt-to-bench/releases/tag/v0.1.0), which is what triggers Zenodo. I'm waiting for Zenodo to mint the DOI; that usually takes a few minutes.

- **Author:** Sebastian S. Cocioba, Binomica Labs. Your ORCID was the only public record matching your name and Binomica Labs: 0000-0002-6821-2996. It's now set in the Zenodo metadata (`.zenodo.json`), `CITATION.cff`, the paper's author line and the MIT copyright line.
- **Competing interests:** the paper now says you're a co-author of McNair et al. 2024 (the COBLE paper, which it cites). Funding is still a placeholder.
- **Release notes:** they say plainly that the two Qwen3.5 runs, the results write-up and the physical validation are still to come. Those will go into the next release, which gets a new DOI under the same concept DOI.

When the DOI appears, I'll add the badge to the README and the DOI to `CITATION.cff`, then push.

Qwen3.5 4B is still finishing its 9 remaining tasks in the background.

<details><summary>2 tool call(s)</summary>

- `Bash` Read Zenodo DOI result — `cat [scratch]`
- `Bash` Fetch the minted Zenodo record details — `curl -s -m 20 "https://zenodo.org/api/records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" | python3 -c …`

</details>

Zenodo minted the DOIs, with your name and ORCID attached. Now I'm adding the DOI badge to the README, a "How to cite" entry, and the DOI in `CITATION.cff`:

<details><summary>1 tool call(s)</summary>

- `Bash` Add DOI badge and citation, push; check run — `python3 - <<'EOF' …`

</details>

Zenodo is set up, and every future GitHub release will be archived automatically.

- **Cite this DOI:** **10.5281/zenodo.23198097**. It's the concept DOI and always resolves to the newest version.
- **This version:** v0.1.0 is 10.5281/zenodo.23198098 (https://zenodo.org/records/23198098). The record lists you as Cocioba, Sebastian S., Binomica Labs, with your ORCID 0000-0002-6821-2996.
- **The repo now has:**
  - a DOI badge at the top of the README;
  - a "How to cite" entry: *Cocioba SS (2026). Prompt to Bench… Zenodo. https://doi.org/10.5281/zenodo.23198097*;
  - the DOI in `CITATION.cff`, so GitHub's "Cite this repository" button picks it up.

  All of this is pushed as `d5802d1`.

A Zenodo record's metadata (description, keywords, funding) stays editable on zenodo.org, but its files are frozen. The full results will go into a `v0.2.0` release, which gets its own version DOI under the same concept DOI.

Qwen3.5 4B is still working through its remaining tasks at about 15 minutes each. The 9B starts only after I've checked the 4B's results.

### 🧑 21:32 UTC

> lets do a hard audit, edge case, and harden and make sure everything is sound mechanically, bioligically, logically, and the prose is tight without meandering too much. I'll add my style later and fill in sections I deem in need of a more human touch. Can we also log the prompts and outputs to something so I can share the meta of building this in real-time?

This has two parts:

1. **A full audit, then fixes.** I'm splitting it three ways:
   - two independent reviewers working in parallel: one on mechanics and biology (real tube, slide and part dimensions, materials, safety), one on logic and claims (every number and claim in the paper checked against the data, code and references);
   - the prose tightening, which I'll do myself.

   All three report back before anything gets edited, so changes stay consistent.
2. **A shareable log of how this was built.** I'll build it while the reviewers work. The session transcript contains private material: your email, other projects visible in your screenshots, your other local models. So the export needs a redaction pass, and nothing gets published until you've seen it.

Launching the two reviewers:

<details><summary>5 tool call(s)</summary>

- `Agent` (sub-agent) Mechanical/biological design audit
- `Agent` (sub-agent) Logic and claims audit
- `Bash` Inspect session transcript structure — `cd ~/.claude/projects/-home-seb-printpaper && ls -la *.jsonl | awk '{print $5, $9}'; f=$(ls -S *.jsonl | head -1); python3 - "$f" <<'EOF' …`
- `Write` ~/printpaper/meta/build_log.py
- `Bash` Generate build log and scan for leaks — `printf '# One literal string per line; each occurrence becomes [redacted] in BUILD_LOG.md\n[redacted]\n[redacted]\ne …`

</details>

One leak check fired. Let me see what it is, and check that the opening of the log looks right:

<details><summary>2 tool call(s)</summary>

- `Bash` Locate leak and preview log start — `grep -niE "[email]|~|[redacted]|[redacted]|gho_|system-reminder|userEmail" meta/BUILD_LOG.md | cut -c1-220; echo ----; sed -n 1,44p meta/B …`
- `Bash` Find how the first prompt is stored — `cd ~/.claude/projects/-home-seb-printpaper && python3 - <<'EOF' …`

</details>

The full prompt is in the transcript, so my exporter is cutting it. Testing the redaction step on that exact text:

<details><summary>1 tool call(s)</summary>

- `Bash` Debug which redaction rule truncates the prompt — `.venv/bin/python - <<'EOF' …`

</details>

Redaction isn't the culprit; the text passes through unchanged. So the problem is in how events are picked up. Listing the first human events the exporter actually emits:

<details><summary>2 tool call(s)</summary>

- `Bash` List first human events emitted by exporter — `.venv/bin/python - <<'EOF' …`
- `Bash` Filter notifications, extend redactions, re-export — `python3 - <<'EOF' …`

</details>

That's 14 real prompts now. One more non-human message slipped through (a sub-agent handback), and one leak check still fires:

<details><summary>1 tool call(s)</summary>

- `Bash` Filter agent handbacks; find remaining leak — `sed -i 's/"<task-notification", "\[SYSTEM NOTIFICATION", "<system-reminder"))/"<task-notification", "[SYSTEM NOTIFICATION", "<system-reminde …`

</details>

The last hit is my own leak-check command, which contains the model name in lowercase. Making the custom redactions case-insensitive:

<details><summary>6 tool call(s)</summary>

- `Bash` Case-insensitive redaction; re-check leaks — `python3 - <<'EOF' …`
- `Bash` Show remaining leak-check hits — `grep -niE "[email]|~|[redacted]|[redacted]|[redacted]|gho_|system-reminder|task-notification|agent-message|userEmail" meta/BUILD_LOG.md | cut  …`
- `Skill` skill=update-config, args=Add a project-level Stop hook in ~/printpaper/.claud
- `Bash` Check settings dir and pipe-test hook command — `ls -la .claude/ 2>&1; echo '{}' | (cd ~/printpaper && .venv/bin/python meta/build_log.py); echo "exit=$?"; stat -c '%y' meta/BUILD_L …`
- `Bash` Write local Stop hook, validate, gitignore it — `mkdir -p .claude && cat > .claude/settings.local.json <<'EOF' …`
- `Bash` Commit exporter (not redact list), check 4B run — `printf '# Private redaction list for meta/build_log.py (it names what it hides, so never commit it)\nmeta/redact.txt\n' >> .gitignore && git …`

</details>

The build log is set up, and its exporter is pushed (`99cf31e`). The two audit agents are still running. Once they report, I'll apply their findings together with my own prose pass in one consistent edit. Qwen3.5 4B is still working through its remaining tasks in the background.

**The build log so far:**
- **Exporter:** `meta/build_log.py` turns this session into `meta/BUILD_LOG.md`, currently about 650 lines covering 13 of your prompts. It includes:
  - your prompts verbatim;
  - my replies;
  - every tool call as one line, folded into expandable sections.

  It leaves out raw outputs, my internal reasoning, screenshots and the context Claude Code injects.
- **Redaction:** it removes your email, home paths, tokens, your other local models' names, and background notifications. My leak scan of the current output is clean. The only matches are my own search strings.
- **Real time:** a Stop hook in `.claude/settings.local.json` (personal, not committed) regenerates the log after every turn, in the background. It only updates the local file and never commits or pushes. The settings folder didn't exist when this session started, so open `/hooks` once, or restart, for the hook to take effect.
- **Not published yet:** `BUILD_LOG.md` itself is uncommitted, so you can read it first. Put any extra private strings in `meta/redact.txt`, one per line; that file stays local because it names what it hides. When you're happy, I'll commit the log and refresh it at each release.

One honest note for whoever reads the log: it shows my mistakes as well, including the overnight run that kept your laptop busy.

### 🧑 21:37 UTC

> just one side note that I co-author'd the McNair 2024 paper :)

Good. The competing-interests line already says that. I'll also flag it where the paper first cites McNair 2024 in the introduction, so readers see the self-citation right away:

<details><summary>1 tool call(s)</summary>

- `Bash` Flag self-citation at first mention, commit — `python3 - <<'EOF' …`

</details>

Done. The paper now flags McNair et al. 2024 as yours in two places:

- **Introduction**, at the first citation: "…a collection of 26 printable lab items, *which this author co-wrote*…"
- **Competing interests:** "S. S. Cocioba is a co-author of McNair et al. 2024, which is cited in this paper."

That's pushed as `0498617`. The audit agents are still running; I'll apply their findings together once both report.

The logic audit is back with 32 findings, several of them serious: a task that fails a correct design, false statements about the protocol, and a tutorial that overstates what local models can do. It also says the verified literature notes were missing. The laptop's reboot probably wiped them from `/tmp`, so I'll check that, then read the full report:

<details><summary>6 tool call(s)</summary>

- `Bash` Check scratchpad contents after reboot — `ls -la [scratch] 2>&1 | head; wc -l [scratch] …`
- `Read` [scratch]
- `Bash` Save logic audit report into the repo — `mkdir -p meta/audits && cp [scratch] meta/audits/ …`
- `Bash` Save design audit report into the repo — `cp [scratch] meta/audits/2026-10-06_mechanical …`
- `Read` ~/printpaper/meta/audits/2026-10-06_mechanical_and_biological.md
- `Bash` Freeze benchmark references; re-validate checker — `mkdir -p bench/reference && .venv/bin/python - <<'EOF' …`

</details>

### 🧑 21:48 UTC

> also how do we ethically state that I co-authored this with claude?

<details><summary>8 tool call(s)</summary>

- `Bash` Loosen funnel volume tolerance; re-validate — `python3 - <<'EOF' …`
- `Write` ~/printpaper/bench/rescore.py
- `Bash` Dry-run rescore of Claude runs — `timeout 900 .venv/bin/python bench/rescore.py main-claude lang-claude --dry-run 2>&1 | tail -15`
- `Bash` Apply rescore to Claude main run — `.venv/bin/python bench/rescore.py main-claude 2>&1 | tail -3 && python3 -c " …`
- `Bash` Locate analyze.py sections to patch — `grep -n "def failure_stage" -A16 bench/analyze.py; grep -n "walls\[len\|\"complete\"\|main_recs = \|lang_recs = \|Printable 1st\|printable b …`
- `Bash` Patch analysis: truncation, renames, dedupe, median — `python3 - <<'EOF' …`
- `Bash` Add outcome tiers, graded table and tier figure — `python3 - <<'EOF' …`
- `Bash` Fix unclosed think stripping, meta; run tests — `python3 - <<'EOF' …`

</details>

A code snippet inside an unfinished `<think>` block is no longer mistaken for the answer, and all 22 tests still pass. Committing steps A–C before the design work:

<details><summary>21 tool call(s)</summary>

- `Bash` Commit audit fixes part I and push — `git add bench/reference bench/tasks.yaml bench/rescore.py bench/analyze.py bench/run_bench.py bench/results/main-claude/results.jsonl meta/a …`
- `Bash` Write v2 benchware designs and test-render — `cd ~/printpaper/designs && cat > benchware/tube_rack_1p5ml.scad <<'EOF' …`
- `Bash` Write v2 tool designs and verify funnel wall — `cd ~/printpaper/designs && cat > tools/gel_comb_10well.scad <<'EOF' …`
- `Bash` Write v2 quick-fix designs and test-render — `cd ~/printpaper/designs && cat > quick-fixes/dshaft_knob_6mm.scad <<'EOF' …`
- `Bash` Write v2 hardware designs, render, check bracket — `cd ~/printpaper/designs && cat > hardware/stirrer_fan_housing.scad <<'EOF' …`
- `Bash` Point tools at library, re-render and re-slice — `python3 - <<'EOF' …`
- `Read` ~/printpaper/figures/design_library.png
- `Bash` Fix enclosure label, re-render, count README lines — `sed -i 's/^  title: Electronics enclosure with push-fit lid$/  title: Electronics enclosure with slip-fit lid/' bench/tasks.yaml && .venv/bi …`
- `Read` ~/printpaper/README.md
- `Read` ~/printpaper/README.md
- `Bash` Recompute language and model comparison statistics — `.venv/bin/python - <<'EOF' …`
- `Bash` Save README tail (citation and references) — `sed -n '/^## How to cite/,$p' README.md > [scratch] && wc -l [scratch] && head -12 /tmp/claude-1 …`
- `Write` [scratch]
- `Bash` Verify Haiku failures and token statistics — `.venv/bin/python - <<'EOF' …`
- `Bash` Splice new README, regenerate tables, check links — `python3 - <<'EOF' …`
- `Bash` Cite Li 2025 in the coupon rule — `python3 - <<'EOF' …`
- `Read` ~/printpaper/figures/fig_tiers_light.png
- `Bash` Locate tutorial passages to correct — `grep -n "makes small free models usable\|capable model on your own\|qwen2.5-coder:7b\|permanent internet\|try writing the numbers\|11.2\|a l …`
- `Read` ~/printpaper/tutorial/README.md
- `Bash` Get real report for the v2 tube rack — `.venv/bin/python tools/scadreport.py designs/benchware/tube_rack_1p5ml.scad | sed -n 1,9p`
- `Bash` Fix tutorial overclaims and worked example — `python3 - <<'EOF' …`

</details>

Next, the tutorial's model advice and its materials and safety section. Reading the current text:

<details><summary>4 tool call(s)</summary>

- `Bash` Show tutorial Part 7 and exercise 5 — `sed -n '/^## Part 7/,/^## Part 8/p' tutorial/README.md; sed -n '/^5. \*\*Team project/p' tutorial/README.md`
- `Bash` Fix tutorial model advice, materials and safety — `python3 - <<'EOF' …`
- `Bash` Update design catalogue for the v2 library — `python3 - <<'EOF' …`
- `Bash` Update bench docs, drop stale figures, run tests — `python3 - <<'EOF' …`

</details>

Those four images are generated outputs that I'm deliberately retiring, and they're regenerated on every run, so force-removing them is safe:

<details><summary>2 tool call(s)</summary>

- `Bash` Remove stale figures, regenerate, run tests — `git rm -qf figures/fig_frontier_*.png figures/fig_pass_rates_*.png && .venv/bin/python bench/analyze.py >/dev/null 2>&1 && timeout 600 .venv …`
- `Bash` Point tests at frozen reference; guard mutations — `sed -i 's|REF = open(os.path.join(ROOT, "designs/benchware/tube_rack_1p5ml.scad")).read()|REF = open(os.path.join(ROOT, "bench/reference/tub …`

</details>

All 22 tests pass. The suite now also fails loudly if a mutation silently doesn't apply, so this kind of drift can't hide again. Committing and pushing:

<details><summary>2 tool call(s)</summary>

- `Bash` Commit audit fixes part II and push — `git add -A README.md bench/README.md bench/analyze.py bench/tasks.yaml bench/test_harness.py designs figures tools tutorial && git status -- …`
- `Bash` Check Qwen3.5 4B run progress — `tail -3 bench/logs/main-local.log; ps -eo pid,etime,args | grep "run_bench.py --run mai[n]" | cut -c1-80`

</details>

I've finished the audit, applied the fixes, rewritten the paper and corrected the tutorial; all of it is pushed. I also set up a log of how the project was built, which is waiting for you to review before it goes public. Two independent reviews ran, one on logic and claims and one on mechanics and biology, and both reports are saved in `meta/audits/`. All 22 robustness tests pass.

**What the audits caught, and what I changed**
- **One task marked a correct answer wrong.** "1.6 mm wall everywhere" on the funnel can be measured two ways; my reference used one, and Sonnet's correct answer used the other. I widened that check and re-scored every saved answer. Exactly one verdict changed, so Sonnet is now 16/16 on the first try. Nothing else moved, which also shows that my mid-study harness changes didn't alter any other score.
- **The benchmark parts and the lab parts are now separate.** The 16 files the benchmark scores against are frozen in `bench/reference/`, so existing results stay valid. `designs/` became lab-ready v2 parts. The main fixes:
  - **Gel tank:** it was unsafe as built, with electrodes above the buffer line and bare wire leaving the walls. The electrodes now sit in grooves under the buffer, it's wide enough for standard 7 cm trays, and the header says "lid and interlock not included, do not power it".
  - **Stirrer:** the magnets would have hit the top plate; it now has standoffs and countersunk screws.
  - **Tube racks:** clearances are wider, since the old holes would have bound.
  - **Tube adapter:** it fits a centrifuge rotor exactly, so it now says "never spin it".
  - **Slide rack:** it now touches slides only at the edges and drains.
  - **Material notes:** ethanol isn't sterilisation, PETG fails with phenol, chloroform and acetone, and agarose should be cooled before it meets a printed comb.

  The library now prints in 32.8 h from 496 g of PLA (about US$12.40).
- **The paper made false statements, now corrected:**
  - "timings are clean" (some runs overlapped other work);
  - "thinking is off" (LFM2.5 reasoned anyway in every reply);
  - Claude running at temperature 0.2 (it runs at the vendor default);
  - the token-cap history wasn't disclosed;
  - truncated replies were counted as "syntax errors".
- **The tutorial claimed small free models were usable.** None passed a single task, so it now says so plainly.

**What the results support**
- **Hosted models:** Sonnet 16/16 on the first try, Haiku 14/16. A paired test can't separate them (p = 0.06).
- **Local models:** none passed a task. A new graded figure shows why:
  - the Qwen2.5-Coder models write OpenSCAD as if it were another language and return identical code after feedback 31–32 times out of 32;
  - the reasoning models run out of tokens;
  - the Gemma 4 models come closest but rarely get the size right.
- **Language:** Haiku in Spanish, Hindi and Swahili shows no detectable effect.
- **Not claimed:** any minimal viable local model, any language effect, any ranking between the hosted models.

**Shared authorship with Claude:** the paper now has an author-contributions statement for you and an AI-use statement that names the model and tool and says what each of you did. Claude is not listed as an author, following COPE and ICMJE guidance. Both statements are yours to edit.

**Build log:** `meta/BUILD_LOG.md` has your prompts, my replies and every tool call, redacted, and it updates after each turn via a local hook. Open `/hooks` once to activate it. It isn't committed yet, so have a read before it goes public.

**Still open**
- **Qwen3.5 4B is still running**, on its 10th of 16 tasks at about 15 minutes each. When it finishes I'll re-score it, refresh the numbers, then decide about the 9B.
- **Smaller items I didn't do:**
  - re-timing models in isolation;
  - mutation tests for the checker;
  - a marker string in the public tasks so they can be detected in future model training data;
  - native-speaker review of the translations;
  - printing and measuring the designs.
- **Two things only you can fill in:** funding information, and anything in the text you want in your own voice.

### 🧑 22:05 UTC

> funding is self-funded, no grants. im an independent researcher at binomica labs but i have no active grant for this. all out of pocket.

<details><summary>1 tool call(s)</summary>

- `Bash` Add funding statement, commit and push — `python3 - <<'EOF' …`

</details>

The funding statement is in the paper and pushed (`f51c7e7`):

> **Funding.** This work was self-funded by the author, an independent researcher at Binomica Labs; it received no grant or institutional funding.
>
> **Competing interests.** S. S. Cocioba is a co-author of McNair et al. 2024, cited here. No other competing interests.

I added "No other competing interests" to close that section out. Delete it if you'd rather not make the statement.

The Zenodo record still has no funding field. Zenodo leaves it optional and you have no grant to list, so it can stay blank.

### 🧑 22:06 UTC

> we should include a brief tutorial on how to set up my exact situation. Claude Code, Prusa MK4, OpenSCAD, and any prompt a person can use to help them set up their own printer + openSCAD since not everyone will have access to prusa printers, claude code subscriptions, etc.

I'll add a setup guide with two tracks:

- **Exact stack:** Claude Code, the Prusa MK4, PrusaSlicer, the OpenSCAD development snapshot and `scadreport`. It includes a ready-made `CLAUDE.md` you can drop into a project folder, so Claude Code follows the whole workflow (render, check, slice) on its own.
- **Any setup:** a copy-paste "setup assistant" prompt for any chatbot and any printer or slicer, plus a printable clearance coupon. The coupon lets anyone measure their own printer's fit tolerances and feed them back into their prompts.

Before writing install commands into a tutorial, I'm checking the current official Claude Code install instructions rather than relying on memory:

<details><summary>5 tool call(s)</summary>

- `ToolSearch` query=select:WebFetch, max_results=1
- `WebFetch` url=https://code.claude.com/docs/en/setup, prompt=List the exact official install commands for Claude Code on
- `Bash` Write and verify the clearance calibration coupon — `mkdir -p ~/printpaper/designs/calibration && cat > ~/printpaper/designs/calibration/clearance_coupon.scad <<'EOF' …`
- `Read` ~/printpaper/figures/designs/clearance_coupon.png
- `Write` ~/printpaper/tutorial/claude-code/CLAUDE.md

</details>

The slice command in that template is the one I used earlier, except for the `-o` short flag, which I hadn't tested. Checking it exists:

<details><summary>1 tool call(s)</summary>

- `Bash` Confirm PrusaSlicer CLI -o flag — `timeout 60 flatpak run --command=prusa-slicer com.prusa3d.PrusaSlicer --help 2>&1 | grep -E "^\s+--output|-o " | head -3`

</details>

Confirmed. Now the setup guide: your exact stack first, then any printer, any slicer and any chatbot, with copy-paste prompts.

<details><summary>1 tool call(s)</summary>

- `Write` ~/printpaper/tutorial/SETUP.md

</details>

Now I'm linking the new guide from the tutorial, the paper's repository box and the design catalogue, and listing the coupon:

<details><summary>1 tool call(s)</summary>

- `Bash` Link setup guide and coupon across docs — `python3 - <<'EOF' …`

</details>

The coupon's row landed after a blank line, which would break the Markdown table on GitHub. Fixing that, then committing:

<details><summary>1 tool call(s)</summary>

- `Bash` Fix table, commit and push setup guide — `python3 - <<'EOF' …`

</details>

I added a setup guide covering both your exact setup and the "whatever you have" route, and pushed it (`0e77486`).

**`tutorial/SETUP.md` has three parts:**

- **A. Your exact setup.**
  - Install commands for Claude Code, the OpenSCAD development snapshot, PrusaSlicer (Flathub on Linux) and this repo. I checked the Claude Code commands against the official docs.
  - An honest note that Claude Code needs a paid plan or an API account (the free claude.ai plan doesn't include it) and is only available in supported countries.
  - How to set up a project folder and how a session runs.
- **B. Any printer, any slicer, any chatbot.**
  - Free options for each piece.
  - The same loop run by hand with a chat window: paste the code into OpenSCAD, press F6, paste any errors back, export the STL, slice.
  - A **setup-assistant prompt** for any chatbot, including free and offline ones. It asks about the person's operating system, printer, slicer, internet access, available AI, materials and experience, then writes a personal setup plan that includes calibration and the "don't print this" list.
- **C. Calibration.** A 15-minute print that ends in a "printer facts" card you paste at the top of every design request.

**Two new files back it up:**

- **`tutorial/claude-code/CLAUDE.md`.** A drop-in project file that makes Claude Code run the whole loop by itself: write the `.scad` file, render it, check it with `scadreport`, fix it, offer a test coupon, and slice for the MK4 when asked. It includes safety rules it won't override (centrifuge parts, high voltage, autoclaving claims). Its "Printer facts" block holds placeholder clearances; fill in your real numbers from the coupon.
- **`designs/calibration/clearance_coupon.scad`.** A plate with six engraved holes from +0.0 to +0.5 mm, plus a 10 mm peg. You find which hole the peg presses into, slides through and drops through. It renders cleanly, and `scadreport` measures the holes at exactly 10.00–10.50 mm.

Everything is linked from the paper, the tutorial and the design catalogue.

**Not yet tested:**

- **The `CLAUDE.md` template.** Its OpenSCAD, `scadreport` and PrusaSlicer commands are the ones used throughout this project, so they work, but I haven't run a fresh Claude Code session with the template. That would use your plan's quota, so I'll only do it if you want me to.
- **The coupon print.** Your MK4 is the obvious first test, and your measured clearances would make a good first printer-facts example in the guide.

## Session b2838b18 (started 2026-10-06 22:13 UTC)

### 🧑 22:13 UTC

> adversarially audit the entire codebase as if you were the fabled Reviewer Number Two. Be ruthless. Fix what needs fixing and check prose for ai-slop since thats not only off-putting but wastes reader's time.

<details><summary>9 tool call(s)</summary>

- `Bash` List tracked files and read memory notes — `git ls-files | head -200 && echo && git ls-files | wc -l && cat ~/.claude/projects/-home-seb-printpaper/memory/*.md`
- `Bash` List non-result files and line counts — `git ls-files | grep -v '^bench/results/.*/code/' && wc -l README.md */README.md *.md docs/* tutorial/* 2>/dev/null | tail -30; git log --one …`
- `Bash` Check running benchmark and file sizes — `ps aux | grep -E 'run_bench|ollama|run_main' | grep -v grep; tail -5 bench/logs/main-local.log; wc -l bench/results/main/results.jsonl bench …`
- `Read` ~/printpaper/README.md
- `Read` ~/printpaper/meta/audits/2026-10-06_logic_and_claims.md
- `Read` ~/printpaper/README.md
- `Agent` (sub-agent) Audit benchmark harness code
- `Agent` (sub-agent) Verify paper numbers vs data
- `Agent` (sub-agent) Audit OpenSCAD designs

</details>

While those run, I'll check one inconsistency I spotted: Sonnet is listed as 16/16 on the first try, yet Table 3/4 show "0/1" repair attempts and "0/17" attempts.

<details><summary>5 tool call(s)</summary>

- `Bash` Inspect rescore logic and Sonnet funnel record — `cat bench/rescore.py && grep -n "lab_funnel" bench/results/main-claude/results.jsonl | grep sonnet | python3 -c " …`
- `Bash` Locate attempt handling in analyze.py — `grep -n "def \|attempts\|wall_s" bench/analyze.py | head -80; python3 -c " …`
- `Read` ~/printpaper/bench/analyze.py
- `Edit` ~/printpaper/bench/analyze.py
- `Edit` ~/printpaper/bench/analyze.py

</details>

Now the prose. I'll start with the tutorial.

<details><summary>4 tool call(s)</summary>

- `Read` ~/printpaper/tutorial/README.md
- `Bash` Read setup guide — `cat tutorial/SETUP.md`
- `Bash` Read contributing and bench docs — `cat CONTRIBUTING.md bench/README.md`
- `Bash` Read designs README, CLAUDE.md, Makefile, gitignore — `grep -n "reference\|designs" bench/build_refs.py | head; cat designs/README.md tutorial/claude-code/CLAUDE.md; cat Makefile; cat .gitignore`

</details>

Now a mechanical scan for slop markers across all prose files:

<details><summary>2 tool call(s)</summary>

- `Bash` Grep prose for common filler phrases — `grep -noiE "—|\bdelve|leverag|robust\b|seamless|landscape|crucial|pivotal|vital\b|empower|unlock|game.chang|it'?s worth noting|importantly|n …`
- `Bash` Apply README prose and overclaim fixes — `python3 - <<'EOF' …`

</details>

Now the other documents:

<details><summary>1 tool call(s)</summary>

- `Bash` Apply prose fixes to tutorial, setup and docs — `python3 - <<'EOF' …`

</details>

I'll check the tutorial's scadreport example against the current design file with one quick render:

<details><summary>1 tool call(s)</summary>

- `Bash` Run scadreport on tube rack design — `.venv/bin/python tools/scadreport.py designs/benchware/tube_rack_1p5ml.scad 2>&1 | head -12; echo; sed -n 1,30p designs/benchware/tube_rack_ …`

</details>

The tutorial example matches the current design. Next: README and SETUP both link `meta/BUILD_LOG.md`, but that file is untracked, so the link is broken on GitHub. Checking why:

<details><summary>2 tool call(s)</summary>

- `Bash` Inspect build log status and generator — `ls -la meta/ && head -30 meta/build_log.py && wc -c meta/BUILD_LOG.md && head -20 meta/BUILD_LOG.md && git log --oneline -- meta/BUILD_LOG.m …`
- `Bash` Compare tutorial prompt with system prompt — `python3 -c " …`

</details>

The starter prompt matches. I'll wait for the three reviewers before changing anything that depends on numbers.

<details><summary>1 tool call(s)</summary>

- `ScheduleWakeup` delaySeconds=1200, reason=Fallback in case the audit subagents hang; their completion , prompt=Continue the Reviewer-2 audit: integrate subagent findings a

</details>

So far I've made the README, tutorial and docs fixes (overclaims, untested-user claims, filler) and the analyze.py fix for stale post-pass attempts. Three reviewers are still checking the harness code, every number against the data, and the designs. I'll merge their verified findings when they report.

The numbers review is in: most claims hold, with eight real discrepancies. Applying the fixes now, starting with the print-time bug and the run script.

<details><summary>1 tool call(s)</summary>

- `Bash` Read slicer script, CSV header, run script — `sed -n 40,97p tools/slice_library.py; head -3 figures/print_estimates.csv; cat bench/run_main_local.sh; grep -n "i\['l'\]\|i\[\"l\"\]" tools …`

</details>

Qwen3.5 9B is in the run script's model list, so "still being completed" stays true. Fixing `hms()` and recomputing the CSV hours from the saved time strings, so nothing needs re-slicing:

<details><summary>2 tool call(s)</summary>

- `Bash` Fix hours parsing and recompute print CSV — `python3 - <<'EOF' …`
- `Bash` Show word-level CSV changes — `git diff --word-diff figures/print_estimates.csv | grep -o '\[-[^]]*-\]{+[^}]*+}' | head -20`

</details>

Applying the remaining numeric and wording fixes from the numbers review:

<details><summary>1 tool call(s)</summary>

- `Bash` Apply numeric corrections across docs — `python3 - <<'EOF' …`

</details>

Now the scadreport inconsistency (circular islands reported by length, holes by area-equivalent diameter):

<details><summary>3 tool call(s)</summary>

- `Bash` Inspect scadreport island formatting — `sed -n 255,275p tools/scadreport.py; grep -n "\"l\"\|'l'\|\"d\":" tools/scadreport.py | head`
- `Bash` Read shape descriptor code — `sed -n 100,120p tools/scadreport.py`
- `ScheduleWakeup` delaySeconds=1200, reason=Fallback while the code and design audit agents finish., prompt=Continue the Reviewer-2 audit: integrate subagent findings a

</details>

The numbers review found eight real discrepancies, and I've fixed them:
- **Print time:** a parsing bug dropped the seconds, so the total is 33.0 h, not 32.8 h.
- **Language results:** McNemar p-values corrected, and some language failures repeat with the same failing check, so "it's all sampling noise" is withdrawn.
- **Smaller fixes:** truncation counts, Sonnet's timing range, the support/bridge claim, the stale enclosure title, the Zenodo "tested" wording, and the timing comment in the run script.

Still waiting on the code and design reviewers.

The design review found real functional problems:
- **Seed template:** no longer fits in a 90 mm dish.
- **Slide rack:** slides lean until neighbours touch.
- **Clearance coupon:** can't measure the "loose" fit the paper recommends.
- **Funnel:** a throat at the spout.
- **Tube rack:** the tutorial's own "change cols" instruction would cut holes through the side of the rack.

Reading the affected files now:

<details><summary>2 tool call(s)</summary>

- `Bash` Read five design files to fix — `cd ~/printpaper/designs && for f in tools/seed_sowing_template.scad benchware/slide_drying_rack.scad calibration/clearance_coupon.sc …`
- `Bash` Test how Customizer reads parameter comments — `cd [scratch] && printf '/* [A] */\n// above desc\na = 11.6;\nb = …`

</details>

Confirmed: trailing comments never show in the Customizer, so none of the 17 files has parameter descriptions there. Testing whether a bare step comment works for spinboxes:

<details><summary>1 tool call(s)</summary>

- `Bash` Test spinbox step annotation syntax — `cd [scratch] && printf '/* [A] */\n// tube body + clearance [mm] …`

</details>

Both work. I'll make the geometry fixes by hand first, then convert the Customizer comments across all files with a script. Starting with the seed template, slide rack, coupon, funnel and hose barb:

<details><summary>3 tool call(s)</summary>

- `Bash` Apply geometry fixes to five designs — `cd ~/printpaper/designs && python3 - <<'EOF' …`
- `Bash` Read remaining designs to fix — `sed -i 's|// centre-to-centre \[mm\]: a 1 mm slide leans <= 8 deg in its slot, so tops stay ~3 mm apart|// centre-to-centre [mm]: a 1 mm sli …`
- `Bash` Apply design fixes and test-render four designs — `python3 - <<'EOF' …`

</details>

All four render cleanly. Measuring the changed parts one at a time:

<details><summary>4 tool call(s)</summary>

- `Bash` Measure changed designs with scadreport — `cd ~/printpaper && for f in designs/tools/seed_sowing_template.scad designs/tools/lab_funnel_60mm.scad designs/benchware/slide_dryin …`
- `Bash` Find multi-assignment parameter lines — `cd ~/printpaper/designs && sed -i 's|^// Print: PLA or PETG, 0.2 mm layers, 20 % infill, no supports.|// Print: PLA or PETG, 0.2 mm  …`
- `Bash` Convert parameter comments for Customizer — `python3 - <<'EOF' …`
- `Bash` Render all designs and check Customizer export — `for f in */*.scad; do r=$(nice -n 19 ~/.local/bin/openscad -o [scratch] …`

</details>

Every design renders without warnings, and the Customizer now shows descriptions and sensible steps. Next, syncing the tutorial's copy of the tube-rack code with the design file:

<details><summary>2 tool call(s)</summary>

- `Bash` Sync tutorial code snippet with design — `cd ~/printpaper && python3 - <<'EOF' …`
- `Bash` Document Customizer comment convention — `python3 - <<'EOF' …`

</details>

Designs done. Now the harness: checks.py and the three weak tasks.

<details><summary>6 tool call(s)</summary>

- `Bash` Inspect checks.py item building and arc — `grep -n "def \|return items\|items.append\|name" bench/checks.py | sed -n 1,80p; sed -n 255,285p bench/checks.py`
- `Bash` Fix duplicate check names and empty arc — `python3 - <<'EOF' …`
- `Bash` Inspect knob task prompt and checks — `grep -n "id: dshaft_knob_6mm" -A32 bench/tasks.yaml | grep -n "prompt\|bore\|deep\|slice\|checks"`
- `Bash` Strengthen comb, pestle and knob checks — `python3 - <<'EOF' …`
- `Bash` Inspect reference_stats function — `sed -n '/^def reference_stats/,$p' bench/checks.py; python3 -c " …`
- `Bash` Make build_refs compare instead of overwrite — `python3 - <<'EOF' …`

</details>

Fixing the checker now: the gel comb, micropestle and knob checks let wrong parts pass. Next I'll add the reviewer's known-wrong parts as permanent regression tests and run the validator.

<details><summary>4 tool call(s)</summary>

- `Bash` Inspect wrong-part repro files — `S=[scratch] ls $S; for f in comb_wrong comb_9teeth pestle1 knob …`
- `Bash` Add mutant tests and run reference validation — `S=[scratch] mkdir -p bench/mutants && cp $S/comb_wrong.scad ben …`
- `Bash` Rename Swahili code files with language suffix — `git diff --quiet bench/reference_stats.json && echo "stats unchanged"; cd bench/results/lang-claude/code/claude_claude-haiku-4-5 && for f in …`
- `Bash` Harden rescore and dry-run hosted runs — `cd ~/printpaper && python3 - <<'EOF' …`

</details>

The hosted runs and Swahili re-check cleanly: no verdict changes, only partial scores move. Applying:

<details><summary>1 tool call(s)</summary>

- `Bash` Apply rescore to hosted runs — `nice -n 19 .venv/bin/python bench/rescore.py main-claude lang-claude 2>&1 | grep -v "^   " ; git status --short bench/results | head`

</details>

Now the remaining run_bench and analyze fixes:

<details><summary>3 tool call(s)</summary>

- `Bash` Inspect run_bench record and analyze main — `sed -n 285,305p bench/run_bench.py; sed -n 372,385p bench/run_bench.py; sed -n '/^def main/,$p' bench/analyze.py | head -70; cat bench/logs/ …`
- `Bash` Inspect remaining code spots — `sed -n 305,312p bench/run_bench.py; grep -n "def replace_block" -A6 bench/analyze.py; grep -n "^def fig_dumbbell\|^def fig_heatmap\|^def fig …`
- `Bash` Apply harness, analysis and repo hygiene fixes — `python3 - <<'EOF' …`

</details>

Quick check: the harness self-test and the analysis script.

<details><summary>2 tool call(s)</summary>

- `Bash` Run harness tests and regenerate analysis — `nice -n 19 .venv/bin/python bench/test_harness.py 2>&1 | tail -8 && nice -n 19 .venv/bin/python bench/analyze.py 2>&1 | tail -12`
- `Bash` Check regenerated README rows — `grep -n "Sonnet 5.5 (hosted) |\|All 16 parts\|Qwen3.5 4B\|slip-fit lid |" README.md`

</details>

The tables regenerated correctly: Sonnet's phantom repair is gone ("0/0"), and the print total reads 33.0 h. Now the README prose about the checker and the rescoring:

<details><summary>1 tool call(s)</summary>

- `Bash` Update README, bench README, CONTRIBUTING for checker changes — `grep -n "These tests show the checks" README.md | cut -c1-80; python3 - <<'EOF' …`

</details>

Seven designs changed geometry, so Table 1 and the design renders are stale. Re-slicing and re-rendering at the lowest CPU priority so the running benchmark is barely affected:

<details><summary>6 tool call(s)</summary>

- `Bash` Re-slice the design library at low priority — `time nice -n 19 .venv/bin/python tools/slice_library.py 2>&1 | tail -18`
- `Bash` Find stale coupon and cost mentions — `grep -n "15.minute\|15 minutes\|0.5 mm\|US\$12\|33.0 h\|496" tutorial/SETUP.md README.md tutorial/README.md designs/README.md CITATION.cff . …`
- `Bash` Update cost, time and coupon wording — `grep -n "US\$12\b\|US\$12 " README.md | cut -c1-20; python3 - <<'EOF' …`
- `Bash` Regenerate tables and design renders — `nice -n 19 .venv/bin/python bench/analyze.py >/dev/null 2>&1; grep -n "All 16 parts\|slide drying rack |" README.md; time nice -n 19 .venv/b …`
- `Bash` Check whether coupon render is generated — `grep -n "calibration\|coupon\|glob" tools/render_designs.py | head`
- `Bash` Inspect render_designs inputs — `sed -n 1,64p tools/render_designs.py | grep -n "tasks\|png\|openscad" | head; git log --oneline -1 -- figures/designs/clearance_coupon.png`

</details>

Re-rendering the calibration coupon image, which was made by hand outside the render script:

<details><summary>2 tool call(s)</summary>

- `Bash` Render coupon image — `sed -n 35,38p tools/render_designs.py; nice -n 19 openscad -o figures/designs/clearance_coupon.png --imgsize 900,700 --viewall --autocenter  …`
- `Read` ~/printpaper/figures/designs/clearance_coupon.png

</details>

The coupon render is correct. One more honesty fix: the README calls the audits "independent", but Claude wrote the code and Claude ran the audits.

<details><summary>2 tool call(s)</summary>

- `Bash` Find 'independent' audit claims — `grep -rn "independent" README.md designs/README.md bench/reference/README.md tutorial/*.md CONTRIBUTING.md | cut -c1-200`
- `Bash` Replace 'independent audit' claims — `python3 - <<'EOF' …`

</details>

Writing the audit record, matching the two existing ones:

<details><summary>1 tool call(s)</summary>

- `Write` ~/printpaper/meta/audits/2026-10-06_reviewer2.md

</details>

Final consistency sweep for stale values:

<details><summary>2 tool call(s)</summary>

- `Bash` Grep for stale values and summarize changes — `grep -rn "32\.8\|push-fit\|p ≥ 0.38\|out of words\|4-12 s\|two independent\|496 g\|lift tab" --include=*.md --include=*.scad --include=*.jso …`
- `ScheduleWakeup` stop=True

</details>

The audit is done and the fixes are in the working tree, uncommitted. The worst problems were a checker that let wrong parts pass and several designs that wouldn't work as built. The full record is in `meta/audits/2026-10-06_reviewer2.md`. The Qwen3.5 4B run was not touched, and heavy jobs ran at the lowest CPU priority.

**Benchmark checker**
- Two gel-comb checks shared a name, so one silently overwrote the other and the 10-teeth check never ran. A 9-tooth comb passed, and so did a comb with 0.5 mm gaps.
- A micropestle with one groove instead of four passed, and so did a knob with a 7 mm bore instead of 12.
- I fixed the checks and saved these four wrong parts in `bench/mutants/`. `build_refs.py` now requires them to fail, and they do. All 16 references still pass.
- `build_refs.py` used to overwrite the frozen `reference_stats.json` every time it ran. It now only compares against it, unless you pass `--write`.

**Data and analysis**
- The Swahili code files lacked a language suffix, so no language run had ever actually been re-checked. They're renamed and re-checked. That re-check and the one on the hosted runs, both with the stronger checks, changed no verdict.
- After the funnel rescore, Sonnet still showed a repair attempt it never would have needed ("0/1", "0/17"). `analyze.py` now drops attempts after the first pass.
- Print time was 32.8 h because the script dropped seconds. With the design changes below it's now 33.7 h, 508 g, about US$13.
- Other corrections:
  - McNemar p-values are now 0.375 and 0.125.
  - The language paragraph is fixed: the NEMA 17 bracket failed in all three translations on the same check, so it isn't just sampling noise.
  - Sonnet's timing is 3.5–11.5 s, and the stale enclosure title and support/bridge claims are fixed.
  - `qwen2.5:1.5b` was missing from the pull script.

**Designs**
- **Seed template:** at 86.7 mm it no longer fit inside a 90 mm dish. It's 82 mm again.
- **Slide rack:** slides leaned about 11° and could touch. Slots are now deeper and wider apart.
- **Clearance coupon:** it couldn't measure the "loose" fit the paper recommends. It now goes to +1.0 mm, and its print time is ~35 min, not 15.
- **Funnel:** there was a throat at the spout.
- **Tube and 50 mL racks:** the tutorial's own "change `cols`" instruction cut holes through the side.
- Also fixed: the hose barb's bore and collar ledge, the rod clip's grip, and polarity marks on the gel tank.
- Customizer: OpenSCAD ignores trailing comments, so no parameter in any design had a description, and decimal values stepped by 1 mm. Both fixed in all 17 files.

**Overclaims and filler**
- Nothing in the paper tests users without CAD training, yet the abstract and conclusion implied it works for them. That's reworded and added to Limitations.
- §3 said the loop matters more than the model, which your own results contradict.
- The audits are no longer called "independent", since Claude audited Claude's work.
- I cut the slogans and padding ("That is all OpenSCAD is", "We hope others will", "literally", the §8 opener) and relabelled untested tips as untested.

**Left for you**
1. When the 4B run finishes, run `python bench/rescore.py main`. That run started with the old checks and is locked, so I couldn't re-check it. Then run `make analyze`. Verdicts are unlikely to change, but scores may.
2. I didn't change `scadreport` or the repetition detector. The local benchmark (4B now, 9B to come) feeds their output back to the models, so changing them would alter the test mid-study.
3. The README links `meta/BUILD_LOG.md`, but it isn't committed, so the link is broken on GitHub. The local results, logs and `summary.csv` that the tables depend on aren't committed either. Please review the build log's redaction before committing it.

Nothing is committed; tell me if you want it split into commits.

The Qwen3.5 4B run has finished, so the lock on the local results is free. I'll do the rescore I had left for you. `results/main` isn't under git, so I'm backing it up first and doing a dry run.

<details><summary>1 tool call(s)</summary>

- `Bash` Back up local results and dry-run rescore — `ps aux | grep run_bench | grep -v grep; tail -3 bench/logs/main-local.log; cp bench/results/main/results.jsonl [scratch] …`

</details>

The dry run changes 24 partial scores and no pass/fail verdicts, with no failed re-renders. Applying it and regenerating the tables:

<details><summary>1 tool call(s)</summary>

- `Bash` Apply local rescore and regenerate README — `nice -n 19 .venv/bin/python bench/rescore.py main 2>&1 | head -1 && nice -n 19 .venv/bin/python bench/analyze.py >/dev/null 2>&1; grep -n "Q …`

</details>

Qwen3.5 4B is now a complete row (0/16, 39 of 48 attempts cut off). I'll update the prose that still calls that run partial:

<details><summary>1 tool call(s)</summary>

- `Bash` Update partial-run prose and audit record — `python3 - <<'EOF' …`

</details>

The Qwen3.5 4B run has finished, so I did the rescore I'd left for you (item 1 on my list). I backed up the local results to the scratchpad first, since `bench/results/main/` isn't under git.

- **Rescore:** all 210 local conversations were re-checked with the corrected checks. It changed 24 partial scores and no pass/fail verdict, and every file re-rendered.
- **Tables:** regenerated. Qwen3.5 4B is now a complete row: 0/16 passed, and 39 of its 48 attempts were cut off by the token cap or a loop.
- **Prose:** updated to match. The abstract and §6.1 now say only the Qwen3.5 9B run is unfinished (2 of 16 tasks). §5.2 and §9 now say every saved attempt was re-checked and only the funnel verdict changed. The truncation sentence now covers four complete runs (still 37–42 of 48 cut off), and the audit record is updated.

Still open from before: the scadreport and repetition-detector fixes wait until the 9B run is done. The build log, run logs and `bench/results/main/` are still uncommitted, so the README's build-log link is broken on GitHub. Nothing is committed yet.

### 🧑 12:07 UTC

> edge case, harden, and release

I'll split this in two: edge-case testing and hardening first, then the release once everything passes. First, checking the repo and release state:

<details><summary>1 tool call(s)</summary>

- `Bash` Check tags, releases, sizes and version metadata — `ps aux | grep -c "[r]un_bench"; git tag; gh release list 2>&1 | head; git remote -v | head -2; git log origin/main --oneline -1; du -sh benc …`

</details>

No benchmark is running, and v0.1.0 is the latest release. I'll hand the harness edge-case work to a subagent while I handle the designs and release prep. The two touch separate files.

<details><summary>1 tool call(s)</summary>

- `Agent` (sub-agent) Edge-case test and harden harness

</details>

While that runs, I'll look for design edge cases: what happens when a student enters extreme values in the Customizer. Listing every design's parameters:

<details><summary>4 tool call(s)</summary>

- `Bash` List parameters of all designs — `cd ~/printpaper/designs && for f in */*.scad; do echo "=== $f"; awk '/^\/\* \[/{p=1} p&&!/^\/\/ /{print} /^(difference|union|linear_ …`
- `Bash` Add parameter asserts and render all defaults — `python3 - <<'EOF' …`
- `Write` ~/printpaper/tools/check_designs.py
- `Bash` Run design edge-case tests — `cd ~/printpaper && PATH=$HOME/.local/bin:$PATH nice -n 19 .venv/bin/python tools/check_designs.py 2>&1 | grep -v "^PASS" ; PATH=$HOM …`

</details>

Two of the three failures are real knob problems. Investigating the knob with scadreport:

<details><summary>4 tool call(s)</summary>

- `Bash` Diagnose knob body count — `nice -n 19 .venv/bin/python tools/scadreport.py designs/quick-fixes/dshaft_knob_6mm.scad 2>&1 | head -8 | cut -c1-250; git stash list | head …`
- `Bash` Bisect knob non-manifold cause — `cd [scratch] && K=~/printpaper/designs/quick-fixes/dshaf …`
- `Bash` Isolate the non-manifold knob feature — `cd [scratch] && P=~/printpaper/.venv/bin/python; R=/home …`
- `Bash` Test D-bore variants for manifoldness — `cd [scratch] && P=~/printpaper/.venv/bin/python; R=/home …`

</details>

The round mouth bore and the D-shaped bore share identical vertices, and those coincident faces break the solid. Testing two fixes:

<details><summary>1 tool call(s)</summary>

- `Bash` Test knob bore fixes — `cd [scratch] && P=~/printpaper/.venv/bin/python; R=/home …`

</details>

Rotating the round section by half a facet fixes it. I'll apply that to the knob, rotating the mouth chamfer to match, and adjust the test case where 13 columns actually fit the SBS footprint:

<details><summary>1 tool call(s)</summary>

- `Bash` Fix knob mesh and rerun design tests — `python3 - <<'EOF' …`

</details>

All 56 design cases pass, and the knob is now one watertight body. I'm adding a `make designs` target and documenting the convention:

<details><summary>1 tool call(s)</summary>

- `Bash` Wire up design tests; scan build log for private data — `python3 - <<'EOF' …`

</details>

The build log isn't clean yet. One string from the private redaction list is still in it, and so is the text `gho_`. Checking both in context:

<details><summary>6 tool call(s)</summary>

- `Bash` Show contexts of redaction hits — `python3 - <<'EOF' …`
- `Bash` Check redaction comment line and contexts — `head -1 meta/redact.txt; python3 - <<'EOF' …`
- `Bash` Check for fragments of private strings in log — `python3 - <<'EOF' …`
- `Bash` Show the matching fragments in context — `python3 - <<'EOF' …`
- `Edit` ~/printpaper/meta/build_log.py
- `Bash` Regenerate build log and rescan for leaks — `echo "[redacted]" >> meta/redact.txt && .venv/bin/python meta/build_log.py | tail -1 && python3 - <<'EOF' …`

</details>

The scans are clean now. Before publishing I'll also read every human prompt in the log, since the log quotes them verbatim:

<details><summary>1 tool call(s)</summary>

- `Bash` Print all human prompts from build log — `awk '/^### 🧑/{p=1; print; next} /^### /{p=0} p && /^>/' meta/BUILD_LOG.md | cut -c1-400`

</details>

The prompts are benign, and Seb asked for this log so they could share how the project was built. One more scan, for paths outside the project:

<details><summary>1 tool call(s)</summary>

- `Bash` Find home paths outside project in log — `grep -oE "~/[A-Za-z0-9._/-]+" meta/BUILD_LOG.md | grep -vE "^~/(printpaper|\.claude|\.local/bin|lab-parts|prompt-to-bench|\.ollama)" | sort  …`

</details>

Clean. Now the release metadata:

<details><summary>2 tool call(s)</summary>

- `Bash` Read citation metadata and previous release notes — `cat CITATION.cff .zenodo.json; gh release view v0.1.0 --json body,name -q '.name, .body' | head -30`
- `Bash` Bump version metadata to 0.2.0 — `sed -i 's/^version: 0.1.0/version: 0.2.0/; s/^date-released: 2026-10-05/date-released: 2026-10-07/' CITATION.cff && grep -n "v0.2 draft" REA …`

</details>

Waiting on the harness agent. Meanwhile, checking the untracked run logs before they get committed:

<details><summary>1 tool call(s)</summary>

- `Bash` Scan logs and results for private paths — `grep -lE "/home/|@[a-z]+\.(com|org)|gho_|sk-ant" bench/logs/*.log bench/results/summary.csv 2>/dev/null; grep -ohE "/home/[^ ]*" bench/logs/ …`

</details>

The logs and results contain no private paths, emails or tokens. Everything else is staged for the release; I'm waiting on the harness agent's report before committing.

The harness agent's report is in. Every non-regression check came back clean. Before releasing, I'll confirm my build-log fix survived its edits and run the full test suite myself:

<details><summary>1 tool call(s)</summary>

- `Bash` Run full test suite before release — `grep -c 'bare "[email]"' meta/build_log.py && export PATH=$HOME/.local/bin:$PATH && nice .venv/bin/python bench/test_harness.py 2>&1 | tail -1 …`

</details>

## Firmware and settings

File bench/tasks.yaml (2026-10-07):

# Prompt-to-Bench task set: 16 biology-lab parts, 4 per category.
# `prompt` is exactly what the model sees (after the system prompt).
# `checks` are hidden; coordinates are in the design frame of `reference`
# (the part as the prompt describes it, lowest point at z = 0).
# Reference values for relative checks (volume, slice areas) come from the
# rendered reference solution - see build_refs.py.

- id: tube_rack_1p5ml
  category: benchware
  title: 24-place 1.5 mL tube rack
  short: 1.5 mL rack
  reference: bench/reference/tube_rack_1p5ml.scad
  library: designs/benchware/tube_rack_1p5ml.scad
  skills: [block, blind holes, 2-D hole grid]
  prompt: >-
    Design a bench rack for 1.5 mL microcentrifuge tubes. It is a solid rectangular
    block 106 mm long (X), 72 mm wide (Y) and 30 mm tall (Z). It has 24 vertical
    holes in 4 rows (along Y) of 6 holes (along X), 16 mm centre-to-centre in both
    directions, with the hole grid centred on the block. Each hole is 11.2 mm in
    diameter and 25 mm deep, open at the top and closed at the bottom, leaving a
    5 mm solid floor.
  checks:
    - bbox: {size: [106, 72, 30], tol: 0.5}
    - bodies: 1
    - slice: {z: 15, islands: 1, holes: 24, hole_d: [11.2, 0.4],
              hole_grid: {nx: 6, ny: 4, px: 16, py: 16}, tol: 0.5}
    - slice: {z: 2.5, islands: 1, holes: 0}
    - volume: {rel_tol: 0.05}

- id: conical_rack_50ml
  category: benchware
  title: 50 mL conical tube rack, printed inverted
  short: 50 mL rack
  reference: bench/reference/conical_rack_50ml.scad
  library: designs/benchware/conical_rack_50ml.scad
  skills: [print orientation, through holes, multi-feature union]
  prompt: >-
    Design a rack for six 50 mL conical (Falcon-type) tubes. It is printed upside
    down and flipped over after printing. In print orientation: a flat plate 130 mm
    (X) by 90 mm (Y) and 4 mm thick lies on the bed (z = 0 to 4). The plate has six
    through-holes, 30.5 mm in diameter, in 2 rows (along Y) of 3 (along X), 40 mm
    centre-to-centre in both directions, centred on the plate. Two solid walls run
    along the two long edges of the plate: each wall is 130 mm long (X) and 4 mm
    thick (Y), flush with the plate's long edge, and rises from the plate to
    z = 70. The two short ends stay open. After flipping, the rack stands on the
    two walls and the tubes pass through the holes.
  checks:
    - bbox: {size: [130, 90, 70], tol: 0.5}
    - bodies: 1
    - slice: {z: 2, islands: 1, holes: 6, hole_d: [30.5, 0.5],
              hole_grid: {nx: 3, ny: 2, px: 40, py: 40}, tol: 0.6}
    - slice: {z: 40, islands: 2, island_rects: [[130, 4], [130, 4]], island_tol: 0.4}
    - probes: {solid: [[0, 43, 40], [0, -43, 40], [0, 0, 2]],
               empty: [[0, 0, 40], [63, 0, 40], [0, 20, 2]]}
    - volume: {rel_tol: 0.05}

- id: slide_drying_rack
  category: benchware
  title: Microscope slide drying rack
  short: slide rack
  reference: bench/reference/slide_drying_rack.scad
  library: designs/benchware/slide_drying_rack.scad
  skills: [thin slots, 1-D array, small clearances]
  prompt: >-
    Design a drying rack that holds 10 microscope slides (75 x 25 x 1 mm) standing
    upright on their long edge. It is a solid base block 90 mm long (X), 45 mm wide
    (Y) and 20 mm tall (Z). Cut 10 parallel slots into the top face: each slot runs
    along X, is 77 mm long, 1.6 mm wide (Y) and 10 mm deep, open at the top. The
    slots are 3.5 mm apart centre-to-centre (in Y), and the group of slots is
    centred on the block in X and Y.
  checks:
    - bbox: {size: [90, 45, 20], tol: 0.5}
    - bodies: 1
    - slice: {z: 15, islands: 1, holes: 10, hole_rect: [77, 1.6, 0.6, 0.25],
              hole_centers: [[0, -15.75], [0, -12.25], [0, -8.75], [0, -5.25], [0, -1.75],
                             [0, 1.75], [0, 5.25], [0, 8.75], [0, 12.25], [0, 15.75]], tol: 0.4}
    - slice: {z: 5, islands: 1, holes: 0}
    - volume: {rel_tol: 0.05}
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

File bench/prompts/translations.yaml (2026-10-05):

# Task prompts translated for the language ablation (system prompt stays in English,
# as when a student pastes the tutorial's starter prompt and writes the spec in their
# own language). Numbers, units, axis names and coordinates are unchanged; decimal
# points are kept so only the language varies.
# Translations were drafted with AI assistance and have NOT yet been reviewed by
# native speakers - corrections are very welcome (see CONTRIBUTING.md).

es:
  tube_rack_1p5ml: >-
    Diseña una gradilla de mesa para tubos de microcentrífuga de 1.5 mL. Es un bloque
    rectangular macizo de 106 mm de largo (X), 72 mm de ancho (Y) y 30 mm de alto (Z).
    Tiene 24 agujeros verticales dispuestos en 4 filas (a lo largo de Y) de 6 agujeros
    (a lo largo de X), a 16 mm de centro a centro en ambas direcciones, con la
    cuadrícula de agujeros centrada en el bloque. Cada agujero tiene 11.2 mm de
    diámetro y 25 mm de profundidad, abierto por arriba y cerrado por abajo, de modo
    que queda un fondo macizo de 5 mm.
  conical_rack_50ml: >-
    Diseña una gradilla para seis tubos cónicos de 50 mL (tipo Falcon). Se imprime boca
    abajo y se le da la vuelta después de imprimirla. En la orientación de impresión:
    una placa plana de 130 mm (X) por 90 mm (Y) y 4 mm de espesor descansa sobre la cama
    (de z = 0 a 4). La placa tiene seis agujeros pasantes de 30.5 mm de diámetro, en 2
    filas (a lo largo de Y) de 3 (a lo largo de X), a 40 mm de centro a centro en ambas
    direcciones, centrados en la placa. Dos paredes macizas recorren los dos bordes
    largos de la placa: cada pared mide 130 mm de largo (X) y 4 mm de espesor (Y), está
    alineada con el borde largo de la placa y sube desde la placa hasta z = 70. Los dos
    extremos cortos quedan abiertos. Una vez volteada, la gradilla se apoya sobre las
    dos paredes y los tubos pasan por los agujeros.
  slide_drying_rack: >-
    Diseña un soporte de secado que sostenga 10 portaobjetos de microscopio
    (75 x 25 x 1 mm) de pie sobre su borde largo. Es un bloque base macizo de 90 mm de
    largo (X), 45 mm de ancho (Y) y 20 mm de alto (Z). Corta 10 ranuras paralelas en la
    cara superior: cada ranura va a lo largo de X, mide 77 mm de largo, 1.6 mm de ancho
    (Y) y 10 mm de profundidad, y está abierta por arriba. Las ranuras están separadas
    3.5 mm de centro a centro (en Y) y el grupo de ranuras está centrado en el bloque
    en X y en Y.
  pcr_tube_rack_sbs: >-
    Diseña una gradilla para 96 tubos de PCR (0.2 mL) con la huella estándar de
    microplaca (ANSI/SLAS): un bloque de 127.76 mm de largo (X), 85.48 mm de ancho (Y)
    y 20 mm de alto (Z). Tiene 96 agujeros pasantes verticales de 6.2 mm de diámetro,
    en 8 filas (a lo largo de Y) por 12 columnas (a lo largo de X), separados 9.0 mm de
    centro a centro. El centro del primer agujero (A1) está a 14.38 mm del borde
    izquierdo y a 11.24 mm del borde trasero, de modo que la cuadrícula queda centrada
    en el bloque. Corta un chaflán de 45 grados con catetos de 5 mm en la arista
    vertical de la esquina de A1 como marca de orientación.
  gel_comb_10well: >-
    Diseña un peine de 10 pocillos para preparar geles de agarosa, impreso tumbado.
    Todo el peine es una placa plana de 1.5 mm de espesor (Z) apoyada sobre la cama.
    Visto desde arriba, tiene un lomo recto (barra trasera) de 70 mm de largo (X) y
    12 mm de ancho (Y), y 10 dientes rectangulares que cuelgan de uno de los bordes
    largos del lomo en la dirección -Y. Cada diente mide 5.0 mm de ancho (X) y 12 mm de
    largo (Y). Los huecos entre dientes vecinos son de 1.5 mm, y la fila de dientes
    está centrada en el lomo en X.
  micropestle_1p5ml: >-
    Diseña un pistilo para moler tejido dentro de un tubo de microcentrífuga de 1.5 mL,
    impreso de pie. De abajo hacia arriba: (1) un mango cilíndrico de 8 mm de diámetro
    desde z = 0 hasta z = 45; (2) un cono que se estrecha de 8 mm de diámetro en z = 45
    a 3 mm de diámetro en z = 62; (3) una punta redondeada: una esfera de 3 mm de
    diámetro centrada en z = 62. Para mejorar el agarre, corta cuatro ranuras
    circunferenciales en el mango, cada una de 2 mm de ancho (en Z) y 1 mm de
    profundidad, centradas en z = 10, 15, 20 y 25.
  lab_funnel_60mm: >-
    Diseña un embudo pequeño de laboratorio, impreso de pie con la abertura ancha
    arriba. Un tubo de salida recto con 10 mm de diámetro exterior va de z = 0 a z = 20.
    Encima, un cono se ensancha desde 10 mm de diámetro exterior en z = 20 hasta 60 mm
    de diámetro exterior en el borde, en z = 50. La pared tiene 1.6 mm de espesor en
    todas partes (así que el orificio del tubo de salida mide 6.8 mm), y el embudo está
    abierto arriba y abajo para que el líquido pase de lado a lado.
  seed_sowing_template: >-
    Diseña una plantilla de siembra que quepa dentro de una placa de Petri de 90 mm: un
    disco plano de 85 mm de diámetro y 2 mm de espesor, apoyado sobre la cama. Tiene una
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

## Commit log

2026-10-05 Prompt to Bench: paper draft, tutorial, 16 lab designs, benchmark harness
    - README.md is the paper (living preprint); results sections are generated
    by bench/analyze.py between AUTO markers
    - designs/: 16 parametric OpenSCAD parts (benchware, tools, quick fixes,
    full hardware), validated by bench/build_refs.py
    - tools/scadreport.py: geometry report for feeding back to any LLM
    - bench/: tasks with hidden symmetry-aware checks, Ollama + Claude CLI
    harness with repair loop, translations (es/hi/sw), analysis + figures
    - tutorial/: hands-on guide for students
    [conical_rack_50ml.scad, dshaft_knob_6mm.scad, enclosure_box_and_lid.scad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]
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2026-10-06 Audit fixes I: freeze benchmark references, fix funnel false negative, rescore
    - bench/reference/: frozen v1 answer keys (designs/ may now evolve for lab use)
    - funnel volume tolerance 15% -> 35%: both readings of '1.6 mm wall everywhere'
    are correct; rescore flips Sonnet funnel a0 to pass, no other verdict changes
    - bench/rescore.py re-checks saved attempts with the current checker (lock-safe)
    - analysis: 'truncated' failure stage, renders-vs-printable wording, cross-run
    dedupe, true median, outcome tiers + graded table + tier figure
    - harness: strip unclosed <think> before extracting code; record git commit;
    no fake temperature in Claude run metadata
    - meta/audits/: the two independe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
    [conical_rack_50ml.scad, dshaft_knob_6mm.scad, enclosure_box_and_lid.scad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]
2026-10-06 Audit fixes II: lab-ready v2 designs, corrected paper and tutorial
    Designs (library only; benchmark keys stay frozen in bench/reference/):
    - tube clearances 0.4-0.5 mm per side (1.5 mL, 50 mL, PCR racks)
    - slide rack: edge-only contact, drain holes, ISO slide size
    - SBS rack keeps the full footprint (radiused corners, raised chamfer)
    - gel tank: 84 mm inside, electrodes in floor/wall grooves under the buffer,
    no holes below the buffer line, explicit 'lid not included, do not power'
    - stirrer: standoffs so magnets clear the plate, countersunk screws
    - adapter: blind bore, 'never in a centrifuge'; knob: round mouth + chamfer;
    funnel: true 1.6 mm wall; bracket: teardrop motor hole; seed tem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
    [conical_rack_50ml.scad, dshaft_knob_6mm.scad, enclosure_box_and_lid.scad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]
2026-10-06 Add setup guide: exact stack, any-printer path, calibration coupon
    - tutorial/SETUP.md: Claude Code + Prusa MK4 + PrusaSlicer + OpenSCAD setup
    (install commands checked against the official Claude Code docs), the same
    workflow with any printer/slicer/chatbot, a setup-assistant prompt, and a
    printer-facts card
    - tutorial/claude-code/CLAUDE.md: drop-in project file that makes Claude Code
    run the design -> render -> scadreport -> slice loop with safety rules
    - designs/calibration/clearance_coupon.scad: 15-minute fit-tolerance coupon
    [clearance_coupon.scad]
2026-10-07 Harden harness and checker; close three false-positive checks
    - Checker: numbered duplicate check names (two comb line checks overwrote each
    other), pinned comb pitch, added pestle groove and knob bore-depth slices,
    empty arcs fail; known-wrong parts in bench/mutants must fail
    - build_refs compares against the frozen reference_stats.json unless --write
    - analyze: drop attempts after a rescored pass, McNemar tests, --runs, code-only
    geometry-as-value count; rescore reports failed re-renders and flips
    - Edge-case hardening and ~75 new tests (encodings, missing tools, bad args,
    damaged results, fake Ollama server); no change on any saved attempt
    - slice_library kept seconds; pull script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
    [conical_rack_50ml_s0_sw_a0.scad, conical_rack_50ml_s0_sw_a1.scad, conical_rack_50ml_s0_sw_a2.scad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]
2026-10-07 Designs: fix fit and function defects, add parameter checks
    - Seed template fits a 90 mm dish again (tweezer slot instead of a tab)
    - Slide rack: deeper slots, wider pitch, drain channels; slides cannot touch
    - Clearance coupon spans 0-1.0 mm so it can find a loose fit
    - Funnel spout throat, hose-barb collar ledge, rod-clip grip, knob mesh
    (41 bodies from coincident bore faces), gel-tank polarity marks
    - Racks size their blocks from the hole grid; assert() on impossible
    parameters; Customizer descriptions and steps; tools/check_designs.py
    [clearance_coupon.scad, conical_rack_50ml.scad, dshaft_knob_6mm.scad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]
2026-10-07 Results: complete Qwen3.5 4B run, rescore all runs, recover Swahili code
    Swahili attempts of lang-claude were saved without a language suffix and
    are renamed so they can be re-checked. Rescoring every saved attempt with
    the corrected checks changed partial scores only, no verdict.
    [conical_rack_50ml_s0_a0.scad, conical_rack_50ml_s0_a1.scad, conical_rack_50ml_s0_a2.scad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]
2026-10-07 Paper v0.2: Reviewer-2 audit, corrected claims and prose
    Removes claims no data supports (no user study; 'independent' audits; the
    loop mattering more than the model), corrects numbers (p-values, print time,
    truncation counts), reports the checker false positives, and publishes the
    build log and the third audit.
2026-10-14 Harness: never score a reply the server broke off mid-stream
    An error event in the middle of a streamed reply (runner crash, model
    unloaded on the Tiiny NPU box, context overflow) used to be recorded as
    stream_error while the partial reply was rendered and scored as the
    model's attempt. It is now retried like a dropped connection and, if it
    keeps failing, the task is skipped without a record so a later run redoes
    it, as bench/README.md already promised. A "thinking is always on" error
    drops the thinking switch and retries. No saved attempt had a stream error,
    so no existing result changes.
2026-10-14 Checker: count real cavities only, free the knob's azimuth, close false-positive gaps
    A third audit (meta/audits/2026-10-14_hardening.md) found one false negative
    in real data and several loopholes.
    - A cavity sealed only by a zero-thickness skin (a cutter ending 5e-15 mm
    short of a face) no longer counts as a separate body: Qwen3-Coder-Next's
    correct funnel failed only on that. Real sealed voids still count.
    - The knob task tries every 1 deg rotation (rotation_step), since its
    prompt fixes the pointer only relative to the flat.
    - New checks: bore rays through every vertical passage, edge probes inside
    and outside features, depth brackets (+-0.6 mm), the comb spine, the knob's
    D re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
2026-10-14 Analysis: per-sample results for the NPU box; guard the paper's tables; build-log privacy
    - analyze.py reports runs with several samples per task (--box-runs,
    --think-runs) per sample: a table, an outcome grid, a size figure and
    summary_tiiny.csv, pooling complete samples only. models.yaml lists the
    Tiiny models (card values) and a "Runs on" column.
    - A mistyped --runs used to empty four README tables and summary.csv; now an
    error. Newest record wins by finish time; needs_rerun records wait for
    their rerun; README blocks need exactly one whole-line marker pair and
    the README is written atomically in UTF-8.
    - build_log.py redacts before truncating, redacts private IPs, MACs and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
2026-10-14 Harness: never score a broken stream, redo flagged conversations, safer files
    - A stream that ends without "done", an IncompleteRead, or a line that is
    not an event is a runtime error (retried, never scored), and a "no
    thinking switch" answer on the last retry no longer crashes the run.
    - Conversations a rescore flagged needs_rerun are redone on resume; finished
    models are skipped without being looked up; duplicate or colliding model
    names are refused; the damaged-line repair is write-then-rename.
    - Decisive OpenSCAD messages survive the cap (feedback with 15 or fewer
    messages is unchanged); message de-duplication is linear; an orphan
    </think> is handled; a failed report no longe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
2026-10-14 Designs: stop parameter combinations that break parts
    Defaults render byte-identical. The funnel no longer fills in silently with
    a narrow spout or thick wall; new asserts for the coupon's edge and labels,
    the enclosure's cable hole, the NEMA bracket's holes and gussets (mount_x,
    mount_y replace mount_pos), the hose barb's collar, seed and drain holes,
    the slide rack's fins and the knob's groove wall; the rod clip's openings
    scale with its rings; the gel tank header names the right wall.
    check_designs.py: more cases, a hollowness check, survives a timeout.
2026-10-14 Docs: a coupon recipe that has holes, a setup that finds its packages, a corrected claim, the third audit
    - Tutorial Part 4 kept the bottom 3 mm of the rack, which has no holes; it
    now keeps the top 3 mm (or changes the design's parameters). Both verified.
    - Setup clones to ~/prompt-to-bench and activates the venv before claude,
    so scadreport finds its packages; python commands use .venv/bin/python.
    - Paper: section 5.2 describes the new checks and the third audit;
    section 6.2's "best local attempt" predated the Reviewer-2 slices.
    - LICENSE paths match the folders.
    - meta/audits/2026-10-14_hardening.md: what was fixed and what was left.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
2026-10-15 RFT: pod-side candidate generator and verifier-filtered harvest
    rft_generate.py samples K OpenSCAD files per prompt from the fine-tune (pod GPU);
    rft_harvest.py scores each against the known-correct reference with rft_score and
    keeps only the matches as training examples. Self-tested: a matching candidate is
    kept (score 1.0), a wrong-dimension one rejected. Completes the rejection-sampling
    loop (generate -> verify -> keep -> retrain) ahead of the first iteration.
2026-10-15 RFT: harden the verifier with a triangle-count floor
    Validated rft_score on 18 real parts + realistic flaws: it accepted all 18
    correct files and rejected all 30%-dimension errors, but bbox/volume/bodies
    missed faceting ($fn too low: hexagonal holes, same size). Added a triangle-count
    floor (a faceted part collapses in triangle count); re-validated 18/18 correct
    kept, all faceting now rejected. Catches a reward gap before any paid RFT run.
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2026-10-17 Held-out distillation for v4: 680 verified examples from 17 non-eval part families
    gen_prompts_clean.py (seed 20261018) -> 680 bench-style prompts, 40 per family (cuvette stand,
    pipette cradle, Petri recess plate, cap wrench, groove block, syringe end block, hex-key block,
    bolt-circle ring, peg board, diffuser frame, slotted shim, riser stand, magnet disc,
    countersunk strip, box divider, cable comb, tubing reel), max token Jaccard 0.364 vs any eval
    prompt. Claude Opus wrote the OpenSCAD; distill.py kept 680/680 (render, watertight, bbox
    within 15%; every bbox error 0).
    build_v4.py now reuses none of v3's distilled examples: those under the gate include
    L-brackets and tube couplers, the same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
2026-10-17 Held-out distillation batch B: 700 verified examples from 14 more non-eval part families
    gen_prompts_clean_b.py (seed 20261020): tripod ring, counterbored spacer, dovetail rail, disc
    base with boss, door wedge, washer set (multi-body), V-groove rest, nut-trap block, split collet,
    cross stabiliser, keyhole hanger, stair block, chamfered base, rounded tag - 50 each, max token
    Jaccard 0.373 vs any eval prompt. Opus wrote the files; distill.py kept 700/700 (render,
    watertight, bbox within 15%; every bbox error 0). build_v6.py adds them x2 to v5 (or v4).
    Claude-Session: https://claude.ai/code/session_01XhRgvWnemh9VC44KZ62h5T
2026-10-17 GPU-tier results: base, v2, v3 at 8 samples; multi-turn report repairs for v5
    The box's model service returned HTTP 502 all afternoon, so the box models were benched on a
    rented A40 (vLLM 0.31, bf16) through bench/ollama_openai_shim.py, same harness and checker,
    16 tasks x 8 samples, 3 attempts each. bench/finetune_table.py reads them on a fixed split:
    8 tasks whose prompts v3's distilled data paraphrased (in-family) vs the other 8 (held out).
    base Qwen3.5-9B pass@8 in 2/8, out 1/8 first-attempt renders 48%
    v2 pass@8 in 1/8, out 0/8 88%
    v3 pass@8 in 5/8, out 1/8 95% (36/64 vs 1/64 samples passed)
    So v3's gains are in-family; the stock base passes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
2026-10-17 Paper §6.4: Table 8 - v3 is in-family, held-out v4 transfers a little; §9 thinking check
    Table 8 reads the box base model and its fine-tunes on a rented GPU (16-bit, 8 samples per
    task) on a fixed in-family / held-out split. v3's distilled descriptions paraphrased 8 task
    prompts (token Jaccard 0.56-0.86): it passes 5 of those 8 and 1 of the other 8. v4, trained on
    680 held-out distilled examples (17 non-eval families, Jaccard <= 0.364), passes the 1.5 mL
    rack (8/8) and the PCR-tube adapter (5/8) - one task more than v2 - and nothing in the held-out
    half. The stock base, thinking off, passes 3 tasks (PCR adapter, seed template, slide rack)
    though only 48% of its first attempts render. Why a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
2026-10-17 Paper: Table 8 complete (base, v1-v7); report repairs give the first clean held-out passes
    GPU tier, 8 samples per task, fixed in-family / held-out split:
    v5 (v4 + 1,500 multi-turn report repairs): 5 tasks, 2 held out - the slide rack 7/8 and
    the 96-hole PCR rack 1/8 (no other model passed it); all 20 passes on the first attempt.
    v6 (v4 + 700 distilled from 14 more held-out families): 5 tasks of the in-family half, as
    many as contaminated v3, without seeing their descriptions; 0 held out.
    v7 (v4's data, 1 epoch): 3 tasks; v1 (v2's data, 1 epoch): 1 - epoch effect inconsistent.
    Fine-tuned models stop listening: after feedback the base rewrote its file 84% of the time
    and won 3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
2026-10-18 Box: imports work through the app's API; the 502 outage was a missing app login
    box_import.py imported v5 (and queues v6) with no click in the app - inspect, then a streamed
    import, empty fields left out as the app does. H34's real cause: after a power cycle the box
    keeps its model services down until someone logs in on the TiinyOS app. H39 documents the API.
    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
2026-10-18 Launcher hardening: supervised guard with fallback cap at boot; podjob for pod jobs
    Boot launcher (guarded_pod_body.py): download via curl/wget/python, checksum-verified; the guard
    runs under a supervisor (back within 30 s if it dies); if it cannot be fetched or verified, a
    fallback hard cap still stops the pod at MAX_HOURS; an image without /start.sh keeps PID 1 alive
    instead of crash-looping.
    Guard: age from /proc (no procps dependency - ps missing used to disable the cap), timeouts on
    nvidia-smi and runpodctl, non-numeric knobs fall back to defaults.
    podjob.py replaces ad-hoc chain scripts: per-run directory and atomic exit file (no shared or
    stale markers), per-name lock (no duplicate ru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
2026-10-18 Launcher audit on real pods: backstop cap at boot, guard lock fix, podjob edge cases
    Boot launcher: the hard cap is now also kept by a plain sleeper started before
    the download, so MAX_HOURS holds even if the guard and its supervisor die.
    Tested: a bad checksum is refused six times, logged, and the pod stops at its
    cap; the supervisor restarts a killed guard in 31 s.
    Guard: its sleeps no longer inherit the lock descriptor. A guard killed mid-sleep
    left an orphaned sleep holding the lock, so recovery took 61 s instead of 30
    (re-tested: 30 s).
    podjob: pull-dir no longer deletes a local directory before receiving (staged,
    verified, --replace moves the old copy aside); status checks the job's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
2026-10-18 Box results for v5/v6; choosing among samples without the answer key
    The box came back (its model service needed the vendor app's login after a
    power cycle). On its NPU, one sample per task, v5 passed 3 of 16 - the slide
    rack (held out), the gel comb and the PCR-tube adapter, all first attempts -
    and v6 passed 1; v1 and v2 had passed none.
    bench/self_consistency.py: render the k samples, keep one from the largest
    group whose parts measure alike (sorted bbox to the mm, volume within 2%) - no
    hidden checks used. It beats the first sample for five models (base 0->1, v3
    4->5, v5 3->4, v6 and v8 1->2) but stays short of pass@8: alike-measuring parts
    can differ in what the checks test, and a mode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
2026-10-18 Batch C: 674 held-out distilled parts (14 new families); repair rejection sampling; podjob stop
    gen_prompts_clean_c.py: 14 part families that are neither eval tasks nor batch
    A/B families - T-slot nut, dial ring, vibration foot, ribbed panel, scoop, cable
    bridge, torus weight, hinge leaf, eccentric cam, star wheel, frustum riser, pull
    handle, tensile dog bone, spoked wheel - every prompt at token Jaccard <= 0.32
    with the eval prompts, and kept out by kind too: no hole-grid plate (seed
    template), no notched edge (gel comb), no collar-sleeve-bore stack (PCR-tube
    adapter), no open walled container, no slotted block. Opus wrote all 674 files;
    all rendered watertight at the described size.
    onpol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
2026-10-18 Batch C on-policy data: v9 and v5 first attempts, failures as repair prompts, v9's repairs (1 at T=0.2, 8 hot), v5's repairs
    674 descriptions from 14 part families no model was trained on, two samples each (RFT tolerances):
    v9 first attempts pass 39.4%, v5 38.4%. Repairs of each model's own failures at the bench's sampling:
    v9 changes its file 39.4% and fixes 2.1% (17/817); v5 16.8% and 0.1% (1/831). Eight hot samples per
    v9 failure solve 157 of 817 (253 passing repairs) -> repair_rft_v9c.jsonl (211 rows, v10's addition).
    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
2026-10-18 v10 in Table 8: its own passing repairs -> 36% file changed, first GPU pass won by repair; v5 seed 1 on batch C
    v10 = v9 + 211 of v9's own repairs that passed on batch C (rejection sampling over repair turns), x2, MASK_EARLIER.
    Bench: 4 tasks (one held out: the 50 mL conical rack, 1/8, which no other Table 8 model passed), file changed after
    36% of feedback messages (v9 27%, v5 15% / 8% in its two runs), score rose 5%, and the first pass won by repair of
    any fine-tune on the GPU (seed template: the report showed the notch near the centre; the next file moved it).
    v5 seed 1 on batch C: first attempts 43% (v5 38%, v9 39%); repairs changed 14% / fixed 0.3% (2/769), against v5's
    17% / 0.1% and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
2026-10-18 Same weights, a better prompt: harness search on batch C lifts the stock 9B from 2 to 6 tasks; nothing reliable for a fine-tune
    bench/harness_search.py compares five harnesses (system prompt x feedback) on 224 batch-C descriptions scored
    against their reference files, never the 16 tasks; the winner was fixed by a rule set before the benchmark run,
    then benched against the standard harness on the same A40 (vLLM 0.31.0), 8 samples.
    stock base: 13% -> 32% within three attempts on batch C (h4 = idioms + 2 examples + checklist feedback,
    56 won / 13 lost, p = 2e-7); 16 tasks 2 -> 6 (5 in-family + slide rack), 6 passes won by repair.
    v9 seed 1: 38% -> 44% (idioms, p = 0.06); 16 tasks 5 -> 3 w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
2026-10-18 v11, two seeds: 4 and 5 tasks, 3 passes won by repair each, no clear gain over v9's better run; nothing on four held-out families
    v11 = v9's data + batch C for ten of its 14 families (474 distilled pairs and 421 of v9 seed 1's own failed
    attempts, x2), four families held out; trained with seeds 0 and 1 on two H100s.
    - Table 8: both runs 3/16 at the first sample, 4 and 5 in eight samples, both with the held-out slide rack and the
    gel comb; file changed after 42% and 44% of feedback, 3 repair wins each.
    - Table 10: with v9 seed 1's harness (h1) both runs passed 3 tasks and won fewer passes by repair.
    - Table 11 (new): the four held-out families for every model, split from existing outcome fi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
2026-10-20 Paper v0.3: 16 open models on an NPU box, the first laptop passes (ternary Bonsai 2 27B, 2/16), release audit
    New §6.5, Tables 12-13 and Figures 5-6: 16 chat models from the Tiiny NPU box's store under the standard protocol
    (Gemma 4 26B 9, 7 and 12 of 16 per sample at 2.4 min a task; every other model 0-6) and nine of the twelve that can
    reason rerun with thinking on and 16,384-token replies (gpt-oss-120b 8 and 9 against 4 and 5). On the laptop CPU,
    Ternary Bonsai 2 27B (PrismML's llama.cpp fork, 7.2 GB) passed 2/16, the micropestle and the PCR-tube adapter, at a
    median of 24 min a task; the one conversation a server fault slowed was redone under a rule fixed beforehand. The
    box sweep is st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
2026-10-20 Checker: clean a mesh that is not watertight before checking it
    OpenSCAD's default Manifold export can leave zero-area sliver triangles where unioned parts meet flush (a spout
    tube standing exactly on a cone's bottom ring). The checker then counted dozens of bodies and no volume, so a
    correct part failed. load_mesh now merges vertices that round together at 1e-5 mm and drops zero-area faces when,
    and only when, the mesh is not watertight.
    rescore.py gains --only-open (re-check only attempts whose recorded mesh was not watertight, the only ones this
    can change). A dry run over all 263 committed runs: 31 attempts change, 3 become passes (all Qwen3.5 9B funnels);
    record and audit in meta/audit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
2026-10-20 Paper v0.3.1: three checker false negatives corrected
    The 31 attempts that the load_mesh clean-up changes were re-scored (rescore.py --only-open). Three become passes,
    all Qwen3.5 9B funnels whose spout stood flush on the cone, one in each of the GPU base model's two standard-
    harness runs and one on the NPU box; the other 28 are failing attempts whose score moved by a check or two.
    Regenerated with the repository's scripts and compared before/after for every run family:
    - Table 8 base: pass@8 in-family 2/8 -> 3/8, samples 5/64 -> 6/64; v8 mean best 0.55 -> 0.56
    - Table 11 stock base h0: 2/8 -> 3/8, 5/64 -> 6/64, passes won by repair 0 -> 1
    - Tables 12-13, Figures 5-6: Qwen3.5 9B on the box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
2026-10-22 Sweep: the NPU box's final results (all 55 jobs)
    The sweep finished on 2026-10-21 at 22:30:51. Added since the v0.3 snapshot:
    - main-tiiny: third standard samples for the 11 models that had two (Qwen3-Coder-Next, gpt-oss-120b,
    Qwen3.6 35B-A3B, Qwen3-Coder 30B, Qwen3.8 27B, Qwen3.6 27B, GLM-4.7-Flash, Qwen3.5 9B, Qwen3.5 35B-A3B,
    Qwen3 30B-A3B Instruct, Ornith-1.0 35B). Round 3 was dropped for gpt-oss-20b, Qwen3 30B-A3B Thinking,
    Qwen3 4B and Qwen3 8B, which passed nothing in two samples.
    - think-tiiny: second thinking-on samples for gpt-oss-20b, Qwen3.6 35B-A3B and Qwen3 30B-A3B Thinking, and
    Qwen3 8B's thinking-on sample.
    Records made before the checker fix reached the sweep's froz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
2026-10-22 Small models: a pre-registered test of seven ways to make them useful
    bench/smallmodels/PROTOCOL.md was written before any method ran on the 16 tasks, and records every freeze
    (sha256) before its test. Round 1, each method developed only on parts outside the benchmark:
    - spec 1, a check written from the request by a laptop model (Gemma 4 E4B): it accepts 70% of right parts,
    but two in three of the parts it accepts are wrong (precision 0.36);
    - scadfix 1.0, 32 rules that rewrite recurring parse errors: offline, laptop first files that render 60 -> 92
    and box tasks passed 74 -> 95 over 33 samples; laptop passes 2 -> 3 tasks;
    - grammar-constrained decoding (llama.cpp): it derails Qwen2.5-Co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
